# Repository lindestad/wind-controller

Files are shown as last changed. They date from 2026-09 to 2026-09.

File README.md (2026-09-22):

# LINDESTAD wind controller

Reproducible ESP32-C3 / Zephyr firmware and KiCad PCB for a four-fan simracing wind simulator.

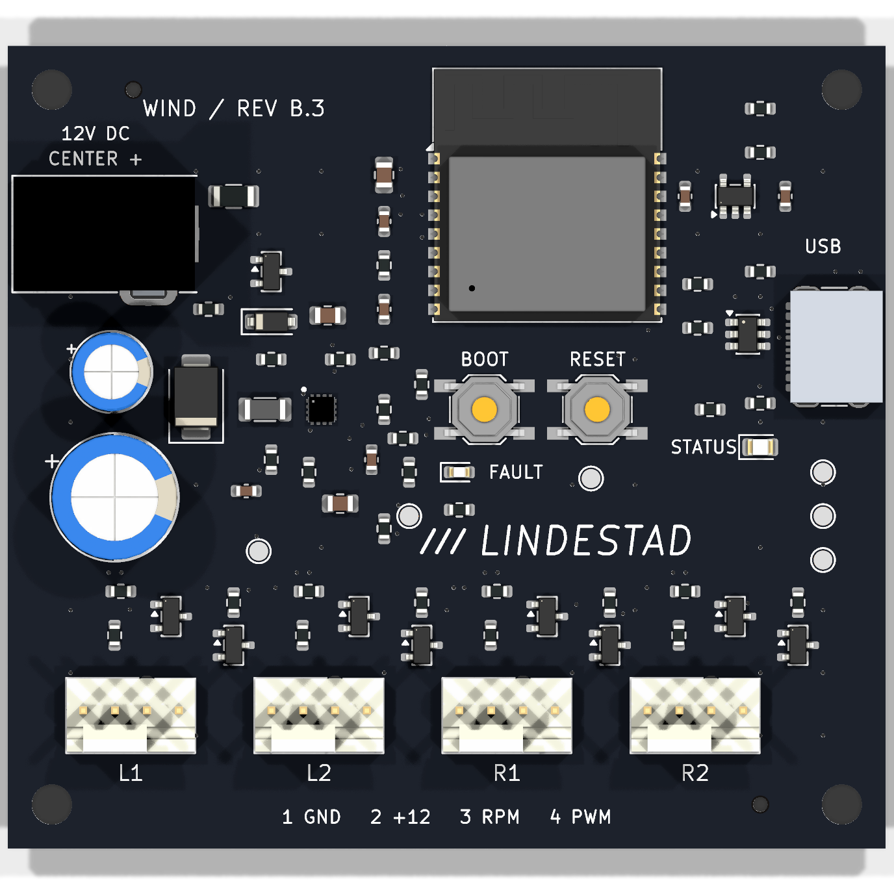
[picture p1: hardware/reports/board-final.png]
Populated WindPCB B.3 CAD render


[Hardware and manufacturing files](hardware/README.md) · [Schematic](hardware/reports/schematic.pdf) · [BOM](hardware/BOM.csv) · [Host integration](docs/host-integration.md)

The images are CAD renderings; representative USB/jack/eFuse models are visual aids.

Zephyr application for WindPCB B.3, ESP32-C3-WROOM-02-N4, four ARCTIC P14 Pro PST fans. Uses native USB Serial/JTAG, four 25 kHz hardware PWM outputs and four tach inputs. No external programmer is required for blank-flash recovery.

The assembled B.3 board is working. On 22 September 2026 it was programmed over native USB, tested with one and then two fans, and integrated with SimHub through Rig Companion. Live full-demand readings were approximately 2,470 and 2,410 RPM (fan rating 2,500 RPM); the user confirmed good airflow after correcting a reversed fan. This is functional bring-up evidence, not calibrated electrical or thermal qualification. See [validation scope](docs/validation.md).

## Repository layout

- `src/`, `include/`, `boards/`: firmware and custom Zephyr board definition.
- `hardware/`: native KiCad project, local libraries/models, BOM, Gerbers, CPL, STEP, PDFs, renders and exporter.
- `scripts/`, `tests/`: dependency setup, build, pin audit, stop-first flash and executable host tests.
- `integrations/simhub/`: source snapshot of the companion's SimHub bridge; no proprietary SDK DLLs.
- `reports/`: historical software/build/bring-up evidence, not a substitute for rerunning checks.

## Build

Windows workspace: `../wind-zephyr`, pinned to Zephyr **v4.4.2**. The required complete Zephyr SDK **1.0.1** is installed under `~/zephyr-sdk-1.0.1`. This project is a separate Git repository; SDK and dependency repositories are outside it.

Install Git, Python 3.12 (including `py`), CMake, Ninja and a host GCC (for the tests; Strawberry Perl's GCC works on Windows). Install the complete **Zephyr SDK 1.0.1** at `~/zephyr-sdk-1.0.1`, or pass its directory with `-Sdk`. Fetch the pinned source dependencies once:

```powershell
./scripts/setup.ps1
./scripts/build.ps1 -Pristine
../wind-zephyr/.venv/Scripts/python.exe tests/test_control.py
```

`build/zephyr/zephyr.bin` is the application build output. Use the Zephyr runner's generated flash configuration rather than guessing offsets. Build provenance and configuration checks are recorded in `reports/`. See `docs/validation.md` for scope and hardware acceptance items.

To recreate dependencies, create a Python 3.12 virtual environment in `../wind-zephyr/.venv`, install `west`, initialize the official Zephyr manifest at v4.4.2, run `west update`, install `zephyr/scripts/requirements.txt`, and run `west blobs fetch hal_espressif`. Use SDK 1.0.1. The frozen manifest is stored in `reports/west-frozen.yml`. No global Zephyr workspace was changed.

## USB and SimHub

Hold BOOT, press/release RESET, release BOOT. The ROM downloader should enumerate through USB-C even if application flash is blank. Connect a data-capable cable; barrel power is unnecessary for flashing. Run `west flash --esp-device COMx` from this workspace with the build directory specified, then press RESET if needed. The exact runner command is documented by `west flash -H -r esp32` and must match the installed esptool version. No eFuse/security programming or UART bridge is required.

For direct integration without Rig Companion, use SimHub **Custom Serial Devices**, sending ASCII `W,<left>,<right>\n` with integer demands 0–1000. The final character is one LF byte. Send every 100 ms or faster, including unchanged values. There is no Arduino/ShakeIt protocol emulation. USB returns the structured status frames below; Zephyr console/log noise remains disabled. Displaying warnings in SimHub needs a receiver/integration; transmission alone does not create a SimHub warning UI.

Zero and demands below 50 stop that side. A nonzero request first precharges for 750 ms, then attempts the commanded headers individually. Each gets a 250 ms full-speed kick; the next starts after at least 500 ms and three new filtered tach edges, or after a 2 s timeout if tach is absent. That timeout raises a per-header warning and advances the sequence, without stopping any output. Losing tach for 2 s after startup also warns while maintaining the requested duty. One to four fans may occupy any headers; no fan-count setting is required. Even zero fans produces warnings rather than a shutdown. Missing headers can delay later fans by 2 s each (up to 6.75 s from command to the fourth header's kick).

An empty header, stalled motor and broken tach wire cannot be distinguished electrically. Warnings mean **no tach while commanded**, not a confirmed missing fan. There are no repeated automatic startup kicks. Three new edges clear a warning; stopping that side clears its warning and the next start checks again. Do not hot-plug fans; switch off supplies before moving connectors.

Every 500 ms, USB transmits `S,1,<mode>,<mask>\n` (8 ASCII bytes). Version is 1; mode is `0` off, `1` precharging, `2` active (including warnings), `3` command timeout, or `4` fault. Mask is one uppercase hexadecimal digit: bits `1/2/4/8` correspond to L1/L2/R1/R2 without tach. For example `S,1,2,A\n` means active, with L2 and R2 warnings. Warnings are live and only apply after a startup attempt, so a clear mask at boot does not prove a fan is connected. STATUS stays lit when fan power is enabled. The red FAULT LED remains controlled by the hardware eFuse, not these firmware warnings.

Status transmission uses a bounded interrupt-driven buffer; a host that stops reading cannot block the control loop or command timeout. Pending reports can be stale after a host pause; a receiver must wait for fresh periodic reports before relying on them. Reports describe requested controller state, not measured fan-supply voltage or verified motor motion.

Only valid complete demand frames refresh the 500 ms command deadline. Overlong, malformed and partial frames are rejected. RX-budget saturation and output failures still stop operation and require reset; warnings do not bypass these protections. Commanded stop sets all PWM inputs low before removing fan power. Abrupt USB loss/reset can still cause the documented brief capacitor-powered twitch/coasting.

## Extended telemetry

Extended telemetry is also sent about once per second: `T,2,<mode>,<warning_hex>,<uptime_ms>,<accepted>,<rejected>,<rpm_L1>,<rpm_L2>,<rpm_R1>,<rpm_R2>,<pwm_L1>,<pwm_L2>,<pwm_R1>,<pwm_R2>\n`. RPM uses edge-count differences over the actual sample interval and assumes two pulses per revolution; absolute accuracy needs independent measurement. PWM values are per-header 0–1000 output demands including startup kicks. No supply voltage/current/temperature measurement exists. The existing S1 reports remain unchanged; consumers should ignore recognized additional report types. Rig Companion now owns USB and receives SimHub vehicle speed through its localhost bridge; see [host integration](docs/host-integration.md).

## Routine firmware updates

After building, use Rig Companion’s **Release USB for firmware update** button (or close any direct serial owner) and run `./scripts/flash.ps1 -Port COM4` (substitute the current port). The helper sends stop commands, requires repeated OFF reports for two seconds, then invokes the generated Zephyr flash runner. It aborts if it cannot confirm OFF. Firmware starts with fan power disabled and needs a new valid demand before running. Never resume the command sender during flashing.

The board's external enable pull-down is intended to keep incoming fan power off in ROM download/reset. This makes leaving 12 V connected a supported design intent for routine updates with the stop-first helper, **not a measured guarantee of no movement**: the MCU cannot measure output capacitor voltage, and reset can release PWM before stored energy drains. Disconnect 12 V whenever zero fan movement matters, or for blank/corrupt firmware recovery. The helper cannot work on older firmware without status reports. Hold BOOT/RESET and use the ordinary Zephyr runner with 12 V disconnected in that case.

The watchdog requests a whole-system reset. The ESP32 driver uses an interrupt stage followed by a reset stage; a configured 500 ms stage interval is approximately 1 s to hardware reset, not a 500 ms reset guarantee. The ordinary command timeout runs separately. No hardware runtime timing guarantee is claimed before measurement.

## Pin map

| Function | GPIO |
|---|---|
| L1/L2/R1/R2 PWM sink gates | 4 / 5 / 6 / 7 |
| L1/L2/R1/R2 tach | 0 / 1 / 3 / 20 |
| Fan power enable | 10 |
| Status LED | 21 |
| Native USB D− / D+ | 18 / 19 |
| BOOT | 9 |
| Reserved boot straps | 2 / 8 |

The DTS uses the WROOM N4 module definition, not a development board with UART0 on GPIO20/21. UART0/1, radios, logging and power management are disabled. The eFuse FLT signal is not wired to the MCU, so firmware cannot classify its faults or measure supply voltage/current.

The LEDC child `inverted` property initializes the stopped output high. Runtime requests use normal polarity and `(1000 − fan_demand) × 40 ns` gate pulse width; the transistor provides the physical inversion. The pinned driver's implementation was checked to distinguish initial idle level from runtime polarity flags.

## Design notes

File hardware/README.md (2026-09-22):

# WindPCB B.3 — editable hardware and manufacturing release

70 × 64 mm, black solder mask, white silkscreen, two-layer 1.6 mm FR-4 / 1 oz copper.
ESP32-C3-WROOM-02-N4; four ARCTIC P14 Pro PST headers; native USB-C; protected 12 V input.

Populated PCB CAD rendering
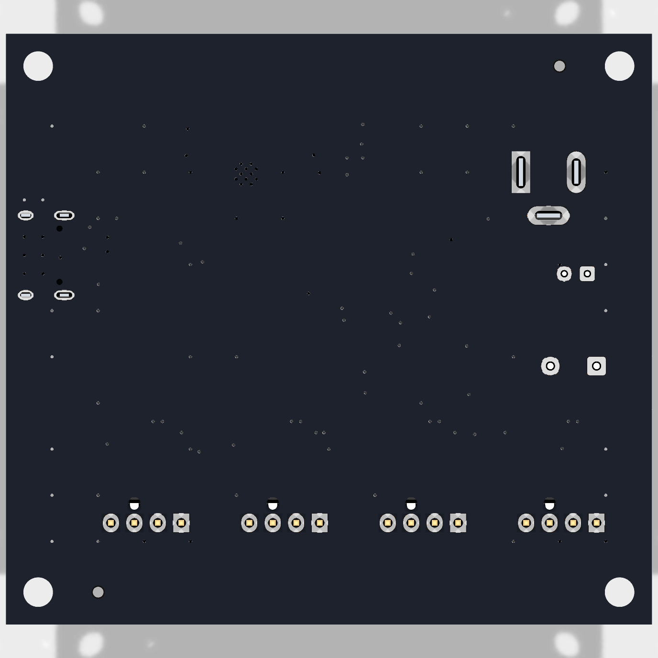
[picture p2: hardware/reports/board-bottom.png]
Underside CAD rendering


These are CAD renders, not photographs. J1, J2 and U4 have representative visual bodies;
their manufacturer drawings and electrical pads govern assembly.

## Reproduce the board

1. Install **KiCad 10.0**, including its standard symbol, footprint and 3D libraries.
2. Open `windpcb.kicad_pro`. All project-specific symbols, footprints and visual models
   are under `libraries/`; library tables use `${KIPRJMOD}`. Standard STEP models use
   `${KICAD10_3DMODEL_DIR}`. No files from the author's KiCad folder are needed.
3. Use [BOM.csv](BOM.csv), [schematic PDF](reports/schematic.pdf) and
   [assembly drawing](reports/assembly-top.pdf) to inspect the release.
4. Fabrication input: [Gerber ZIP](manufacturing/windpcb-revb-gerbers.zip), including
   copper, masks, silkscreens, outline, separate PTH/NPTH drilling and front paste.
5. Full assembly inputs: [PCBA BOM](manufacturing/assembly/PCBA-BOM.csv) and
   [PCBA CPL](manufacturing/assembly/PCBA-CPL.csv): **70 placements, 33 MPNs,
   63 SMT + 7 through-hole**. Do not use the SMT-only files for full assembly.
6. Select black mask / white silk, lead-free HASL, top-side assembly, and customer-added
   tooling holes. Retain individual placement review. Firmware is flashed afterward.

J1 takes a **5.5 × 2.5 mm centre-positive 12 V** barrel plug. Use a regulated supply
with sufficient startup margin (at least 3 A recommended). Each fan has its own header;
leave PST daisy-chain sockets unused. Pin order: **1 GND, 2 +12 V, 3 tach, 4 PWM**.

## Placement and process review

The included CPL is the original submitted file, with explicit connector/capacitor
insertion-origin offsets. **JLC subsequently corrected several component orientations
in its own assembly system. The final numeric machine placement file was not supplied.**
This release therefore requires a fresh supplier placement review; uploading the CPL
alone does not reproduce that approval. Verify every polarized part/pin 1 against the
native CAD and assembly drawing, especially Q1–Q9, U2/U3/U4, J2–J6, D1–D4 and C6/C9.
The first assembled board has since operated successfully with the firmware.

U4 TPS25970LRPWR has ten electrical terminals, even when a supplier's generic visual
model shows sixteen leads. Its 16 split paste apertures are intentional. Preserve the
TI-derived RPW0010A lands and 0.100 mm stencil prescription; ask the assembler to review
the eFuse, USB-C, and ESP32 thermal-via soldering process for its selected finish.

H1–H4: 3.2 mm M3 mounting holes, 63 × 57 mm spacing. H5/H6 are 1.152 mm NPTH tooling
holes with 0.148 mm mask expansion. Their centres are (10, 3.5) and (60, 60.5) mm from
the upper-left corner. The CPL origin is the lower-left corner; X right, Y up.

## Regenerate and verify

Run the exporter with KiCad's Python (which provides `pcbnew`). On Windows:

```powershell
& 'C:/Program Files/KiCad/10.0/bin/python.exe' -m pip install --target hardware/tools/vendor -r hardware/tools/requirements.txt
& 'C:/Program Files/KiCad/10.0/bin/python.exe' hardware/tools/export.py
```

On another installation, put `kicad-cli` on PATH or set `KICAD_CLI` and use a Python
environment that can import KiCad 10's `pcbnew`. The exporter runs ERC, full DRC with
schematic parity, checks every pad/net, exports manufacturing files/BOM/CPL, PDFs,
board-only STEP, pictures and SHA256 hashes. It does **not** rebuild or reroute the PCB.
Historical one-time layout generators were deliberately not included as build steps.

Engineering specifications and revision notes are in `docs/`. Their pre-order wording
and references to historical local reports describe earlier reviews, not the current
hardware test status. The root README and `docs/validation.md` describe current tests.
Private supplier order/account records are not part of this public release.

Sources: [TI TPS2597](https://www.ti.com/lit/ds/symlink/tps2597.pdf),
[ARCTIC P14 Pro PST](https://support.arctic.de/p14-pro-pst),
[JLC tooling guide](https://jlcpcb.com/help/article/how-to-add-tooling-holes-for-pcb-assembly-order).

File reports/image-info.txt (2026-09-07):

esptool v5.4.0
Image size: 133780 bytes
Detected image type: ESP32-C3

ESP32-C3 Image Header
=====================
Image version: 1
Entry point: 0x40381344
Segments: 3
Flash size: 4MB
Flash freq: 80m
Flash mode: DIO

ESP32-C3 Extended Image Header
==============================
WP pin: 0xee (disabled)
Flash pins drive settings: clk_drv: 0x0, q_drv: 0x0, d_drv: 0x0, cs0_drv: 0x0, hd_drv: 0x0, wp_drv: 0x0
Chip ID: 5 (ESP32-C3)
Minimal chip revision: v0.0, (legacy min_rev = 0)
Maximal chip revision: v655.35

Segments Information
====================
Segment   Length   Load addr   File offs  Memory types
-------  -------  ----------  ----------  ------------
      0  0x01554  0x3fc886c0  0x00000018  DRAM, BYTE_ACCESSIBLE
      1  0x086b0  0x40380000  0x00001574  IRAM
      2  0x00024  0x50000000  0x00009c2c  RTC_IRAM, RTC_DRAM

ESP32-C3 Image Footer
=====================
Checksum: 0x3f (valid)

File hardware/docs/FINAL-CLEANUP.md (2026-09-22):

# Revision B — final labels and solder-pad correction

Historical revision B document. The executed review is in [REPORT.md](reports/preorder-review/REPORT.md); current B.1 corrections and validation are in [REVIEW-RESOLUTION.md](REVIEW-RESOLUTION.md).

6 September 2026, after the $82.72 quotation. Current board/manufacturing files supersede the uploaded Gerbers. No new quote or order was submitted in this cleanup.

## Labels and test point

TP5 (FAULT_N) moved 3.5 mm right: (43, 34.5) to (46.5, 34.5) mm from the top-left outline. FAULT is now right of D4, aligned with the LED; STATUS is left of D3. The FAULT_N branch and nearby 3.3 V track bends were adjusted locally and pours refilled. Position metadata is updated. Circuit topology, values, outline and SMT placements did not change.

## Missing 3D body

The boxed component is **U4, TPS25970LRPWR**, the fan-power protection IC. Its ten numbered pads, nets, custom footprint, schematic symbol, BOM entry C3662801 and SMT placement are present. It has no attached 3D model, so KiCad displays lands without a body. JLC included U4 in the quote. J2 also lacks a local 3D body. Neither absence means an omitted component; use manufacturer dimensions to review mechanical envelopes.

## Underside rings: real solder-mask defect

The soldered through-hole pads had copper layers but **no F.Mask or B.Mask openings**, in both board and project footprint copies. The copper itself was not unusually narrow; mask would cover the soldering surface. The render exposed a genuine manufacturing defect that the earlier clean ERC/DRC did not detect.

Restored both-face mask openings with **0.05 mm expansion per edge** for all 23 hand-solder joints and four USB-C shell pads. Updated local libraries as well as the board. Copper sizes, drills and paste geometry are unchanged. U1's deliberately covered thermal holes are excluded.

| Feature | Copper pad, mm | Hole/slot, mm | Narrowest nominal ring |
|---|---|---|---:|
| J3–J6 fan contacts | 2.03 × 1.73 | 1.02 round | 0.355 mm |
| C6 | 1.60 × 1.60 | 0.80 round | 0.400 mm |
| C9 | 2.00 × 2.00 | 1.00 round | 0.500 mm |
| J1 contact 1 | 4.60 × 2.00 | 3.60 × 1.00 slot | 0.500 mm |
| J1 other contacts | 4.20 × 2.00, rotated as appropriate | 3.20 × 1.00 slot | 0.500 mm |
| J2 shell tabs, factory assembly | 2.10 × 1.00 or 1.60 × 1.00 | 1.70 × 0.60 or 1.20 × 0.60 slot | 0.200 mm |

These are nominal dimensions before fabrication tolerances. The 0.355–0.500 mm hand-solder rings provide enough nominal land to retain the copper geometry; mask exposure was the required correction. USB shell pads retain their narrower connector lands, now exposed. Ground thermal reliefs remain. NPTH mounts/locators/tooling holes did not acquire copper.

## Verification and release

- Regenerated ERC, full DRC/parity and exact pad-net comparison: pass, no violations or unconnected items.
- Audited all 27 soldered PTH pads in board and local libraries for mask layers/expansion.
- Parsed both mask Gerbers and checked **54 pad openings**, coordinates and aperture dimensions. See `reports/solder-pad-mask-audit.json`; `tools/validate_b.py` repeats this audit.
- Inspected updated top/underside renders, including LED labels and exposed solder surfaces.
- Regenerated Gerbers, drills, drawings, board-only STEP, previews and hashes. BOM and SMT CPL remain identical to the quoted versions; TP5 has no purchased component.
- Added `PREORDER-REVIEW-PLAN.md`, a proposed agent review and testing workflow that has not been executed.

Old quoted files/manifest are in `reports/jlcpcb/quoted-inputs/`. Use the current `manufacturing/windpcb-revb-gerbers.zip` for a later submission; the JLC draft still contains older Gerbers. A.1 is retained unchanged and has not received this fix. Cost inputs are unchanged, but a revised live price has not been verified.

Corrected underside

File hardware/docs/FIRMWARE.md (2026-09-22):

# Zephyr and SimHub interface

Hardware revision B.3 uses ESP32-C3-WROOM-02-N4 (4 MB flash). Firmware is implemented in the separate local Git repository [wind-controller](../../README.md), commit `6777767`. On 7 September 2026 the actual custom-board build passed with Zephyr v4.4.2 and SDK 1.0.1; 19 host tests and 42 generated-build/hardware-pin checks passed. This is software feasibility evidence, not a test on manufactured hardware. The native USB Serial/JTAG peripheral supports the ROM downloader independently of application firmware; no external USB-UART or debug probe is required.

## Pin map

| Signal | ESP32-C3 GPIO | Module pad | Behaviour |
|---|---:|---:|---|
| L1 PWM drive | 4 | 3 | Transistor gate, inverted relative to fan PWM |
| L2 PWM drive | 5 | 4 | Same |
| R1 PWM drive | 6 | 5 | Same |
| R2 PWM drive | 7 | 6 | Same |
| Fan power enable | 10 | 10 | High enables eFuse; external pull-down and RC |
| L1 tach | 0 | 18 | Non-inverting MOSFET-translated input, 2.2k to 3.3 V |
| L2 tach | 1 | 17 | Same |
| R1 tach | 3 | 15 | Same |
| R2 tach | 20 | 11 | Same; do not enable UART RX here |
| Status LED | 21 | 12 | High lights green LED; ROM UART TX may pulse it |
| USB D− | 18 | 13 | Dedicated native USB |
| USB D+ | 19 | 14 | Dedicated native USB |
| BOOT | 9 | 8 | Pull-up, button shorts to ground |
| Other boot straps | 8 / 2 | 7 / 16 | Pull-ups; reserve these GPIOs |
| RESET | EN | 2 | Pull-up/RC, button shorts to ground |

The red FAULT LED and TP5 report the eFuse fault signal. **It is not connected to an MCU input.** The hardware has no voltage ADC, current telemetry or automatic fault classification. Tach readings can detect a fan that remains stopped after a commanded startup, but cannot identify every cause.

## First flash and recovery

1. Connect USB-C with a data-capable cable; barrel power is unnecessary.
2. Hold BOOT, press and release RESET, then release BOOT. This enters the ROM USB downloader even with blank or broken firmware.
3. Flash through the enumerated USB serial port using Zephyr's Espressif runner/esptool. The implemented custom board target is `wind_controller/esp32c3`, with 4 MB flash and this pin map. Build instructions and generated-runner evidence are in the firmware repository.
4. Press RESET to run. If the runner leaves the C3 in download mode, use its documented watchdog-reset option or press RESET; ordinary serial RTS/DTR assumptions from USB-UART boards do not always apply.

Do not disable ROM download mode, USB Serial/JTAG, or burn security eFuses during ordinary provisioning. Do not use deep sleep, which can disconnect native USB. A COM port is expected; arbitrary USB HID/composite emulation is not the purpose of the C3's fixed Serial/JTAG peripheral.

## Required application behaviour

- Disable radios and configure the native USB Serial/JTAG UART driver; do not blindly reuse the DevKitM external UART console configuration. Keep diagnostic logging out of the command stream.
- Leave fan enable low during all initialization. Configure four LEDC PWM outputs at 25 kHz, initially with their **GPIO gates high**, which holds the fan PWM pins low. Enable power only after a valid command. Hold all four PWM pins at zero for 750 ms after enable, allowing the approximately 364 ms nominal ramp to finish. Then start individual fans as described below; actual spin-up takes longer.
- A 100% fan command means the transistor remains off (gate low). A 0% fan command means gate high. PWM flags or duty conversion must account for this inversion exactly once.
- Use hardware PWM, not a thread repeatedly toggling GPIOs. All four outputs use the same frequency and can share a suitable timer.
- Tach inputs are independent. Start with two pulses per revolution, verify on the actual fans, and calculate `RPM = pulse_frequency × 30` only after that verification. Debounce/filter implausibly short pulses in software.
- Never start on enumeration, console noise, malformed input or button use alone. Reject out-of-range values and overlong frames. Use a whole-system watchdog reset, no GPIO hold and no retained PWM/enable state. CPU-only reset is insufficient. Verify the actual reset domain and pin waveforms on hardware.
- Initial command timeout: 500 ms. On timeout, command PWM stop and disable fan power. No endless fault auto-retry. Output capacitance discharges over time; electrical power removal is not instantaneous.

## SimHub contract

Use **Custom Serial Devices**, with the implemented frame `W,<left>,<right>\n`, where both values are integers 0–1000. Examples: `W,0,0\n`, `W,500,500\n`, `W,1000,700\n`. The `\n` here denotes an actual LF byte, not two literal characters. End-to-end SimHub/USB operation remains a first-board check.

Send complete fresh frames at 10 Hz or faster, even if unchanged; disable Changes only. A paid SimHub configuration may use 20 Hz. Malformed or partial traffic must never refresh the 500 ms timer. Map left to L1/L2 and right to R1/R2. SimHub's actual wind-effect expressions and the Zephyr parser must be implemented and tested together. A serial port alone does not implement SimHub's Arduino/ShakeIt protocol; no compatibility with that protocol is claimed.

References: [Zephyr ESP32-C3](https://docs.zephyrproject.org/latest/boards/espressif/esp32c3_devkitm/doc/index.html), [Espressif native USB](https://docs.espressif.com/projects/esp-idf/en/stable/esp32c3/api-guides/usb-serial-jtag-console.html), [SimHub Custom Serial Devices](https://github.com/SHWotever/SimHub/wiki/Custom-serial-devices).

## B.1 startup, stop and fault sequence

The following contract is implemented in the separate firmware repository. Updated 22 September 2026: missing/stalled tach is a warning rather than a global shutdown, allowing any number of fans. The current firmware passes 25 host tests and 43 build checks and has been flashed and USB-tested on the first board. See the firmware repository's `docs/validation.md` for exact physical-test scope.

1. Earliest initialization: FAN_ENABLE low, four PWM sink gates high, radios disabled. Disable UART0 on the reused tach/status pins and reserve the native USB pins. Do not assert fan enable in bootloader or console initialization.
2. A complete valid nonzero frame starts PRECHARGE: keep all fan PWM pins low, assert enable and wait 750 ms. Continue processing command freshness throughout the wait; never sleep in a way that blocks the safety loop. Zero/zero or a 500 ms timeout immediately takes the stop path.
3. Attempt one commanded header at a time, in L1, L2, R1, R2 order. Apply a 250 ms 100% startup kick, then transition to requested duty. Advance after three new filtered tach edges and at least 500 ms, or after 2 s without qualified tach. On timeout set a no-tach warning for that header and continue starting the others; keep its requested PWM without repeated kicks. These provisional timing limits must be calibrated on the actual P14 Pro PST. Skip a stopped side.
4. Valid recurring frames update targets/freshness without restarting the precharge timer or startup stage. If a previously stopped fan is requested while others run, pass it through the same sequential startup queue. Never assume simultaneous motors' startup current equals their rated current.
5. Stop path: drive all four sink gates high (fan PWM = 0%), then deassert enable. A safety-loop service interval at most 10 ms gives an intended stale-command response within 510 ms of the last completed valid frame. Keep PWM low while logic power remains. On abrupt reset or USB loss, stored capacitor energy may cause a brief twitch/coasting; no instantaneous mechanical-stop promise is made.
6. Tach loss for 2 s raises a per-header warning and leaves outputs running. Three new edges clear it; stopping a side clears its warnings and a later start checks again. Missing fan, stall and broken tach wire cannot be distinguished. RX-budget exhaustion and actuator failures still stop operation and require reset. U4 FLT is not connected to the MCU, and OVLO does not assert FLT: tach alone cannot classify power faults. OVLO may require barrel power cycling.
7. Feed the hardware watchdog only when the control/safety loop is healthy. Logging, USB congestion or parser work must not block deadlines. On recovery discard buffered commands. The simple W frame has no session authentication or anti-replay claim; neither is required for this locally connected accessory.

Tach polarity is unchanged by the common-gate level shifters. Two pulses/revolution remains a first-board measurement, not a guaranteed value inferred from connector convention.

USB now transmits `S,1,<mode>,<mask>\n` every 500 ms using bounded interrupt-driven TX. Mode 0=OFF, 1=PRECHARGE, 2=ACTIVE (possibly warning), 3=STALE, 4=FAULT. Mask is one uppercase hexadecimal digit with L1/L2/R1/R2 bits 1/2/4/8. Console logging remains disabled. A warning display in SimHub requires receiver integration. STATUS still indicates requested fan power; FAULT is still the independent hardware LED.

For routine updates, the firmware repository provides `scripts/flash.ps1 -Port COM4`: send stop, require repeated OFF reports for two seconds, then run the generated Zephyr flash command. USB powers the MCU independently of the 12 V fan rail, so normal 12 V power may remain connected during flashing. ROM recovery is retained and no security/eFuse settings are changed. Reset may allow brief residual fan movement; unplug 12 V if no movement is required. The helper cannot confirm OFF on older, blank or broken firmware; use BOOT/RESET recovery in that case.

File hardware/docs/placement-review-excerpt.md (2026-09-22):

# Factory placement reference (8 September 2026)

The final factory-adjusted placement was reviewed for all 70 components. The submitted CPL was not rewritten after JLC adjusted it. Always review a new supplier placement against the schematic and pads.

## U4 — the component in the user's image

The assigned part is **TI TPS25970LRPWR, C3662801, VQFN-10-HR, 2 × 2 mm**. Its model in the viewer has sixteen decorative perimeter leads. Those are not the physical terminal pattern and must not be used to rotate the component.

With the model hidden, the actual land pattern has the correct ten electrical terminals: four small terminals on each side and two long inner power lands. It agrees with TI's RPW0010A land-pattern drawing. The model is centered over that pattern; its marking is in the upper-left corner, consistent with the required real pin-1 location. This supports the displayed orientation; the generic model cannot demonstrate the shape of every hidden terminal.

Required pin map, also verified against the native board:

| Position | Pin and function |
|---|---|
| Upper-left | 1 EN, at (24.1, 28.3) |
| Left side downward | 2 OVLO, 3 DNC, 4 FLT |
| Inner long land, left | 5 IN |
| Inner long land, right | 6 OUT |
| Right side upward | 7 DVDT, 8 GND, 9 ILM, 10 ITIMER |

The processed PCB CAM archive retains **16 split paste openings** around U4; these are stencil apertures, not sixteen electrical pins. All 199 paste features and all 22 custom paste-symbol geometries are unchanged between its original and edited CAM steps after resolving reordered symbol indices.

**Disposition:** no U4 rotation or footprint change indicated. The rendering mismatch is visual. The actual laser-cut stencil thickness and assembly machine program are not established by the PCB CAM archive or this generic overlay.

Evidence: [U4 with model](U4.png), [actual U4 lands](U4-pads.png), [processed copper](u4-factory.png), [paste audit](paste-audit.json), [TI RPW land drawing](../preorder-review/reviewer-c/sources/tps2597-p52.png), [TI datasheet](https://www.ti.com/lit/ds/symlink/tps2597.pdf).

## Orientation and polarity findings

| References | Final observation and result |
|---|---|
| Q1 | Correct: pin 1/gate upper-left, pin 2/source lower-left, single pin 3/drain right. All three leads overlay the intended pads. The original 180° mismatch is resolved. |
| Q2, Q3, Q4, Q5 | Each individually checked: gate upper-left, source/GND lower-left, drain/PWM right; leads aligned. |
| Q6, Q7, Q8, Q9 | Each individually checked: gate/+3V3 upper-left, source/MCU tach lower-left, drain/fan tach right; leads aligned. |
| U2 | Correct: two terminals at top, three at bottom; pin 1/VIN bottom-left, pin 2/GND bottom-middle, pin 3/EN bottom-right, pin 5/VOUT top-left. |
| U3 | Correct: three terminals on each side, pin 1 upper-left. Pin 2/GND left-middle, pin 5/VBUS right-middle. All six leads aligned. |
| U1 | Correct: antenna toward top edge; module pin 1 upper-left; both nine-pad perimeter rows aligned. The decorative shield dot at bottom-left is not module pin 1. |
| J1 | Correct part DC-005-5A-2.5/C381115; opening left. Asymmetric terminal layout agrees: center-positive pin 1 right, switched pin 2 left, sleeve/GND pin 3 below. |
| J2 | Correct HRO TYPE-C-31-M-12/C165948, opening right. The final drawing's signal contacts overlap their lands; both locating-post markers register with the holes and all four shell features register with their slots. No remaining offset requiring a shift was found. See qualification below. |
| J3, J4, J5, J6 | Each individually checked: electrical pin 1 at left, then +12V, RPM, PWM. Friction lock faces the bottom board edge. Locating feature is above pin 3, over the intended NPTH, rather than on the opposite side as in the old preview. |
| C6 | Positive lead at left (7,26); negative at right (9.5,26). Positive marker and right-side negative stripe agree. |
| C9 | Positive lead at left (6,36); negative at right (11,36). Positive marker and right-side negative stripe agree. |
| D1 | Cathode/band **left**, connected to VIN_PROTECTED; anode right to RP_GATE. Correct. |
| D2 | Cathode/band **bottom**, connected to VIN_PROTECTED; anode top to GND. Correct; the downward cathode is intentional. |
| D3 | Cathode **left** to GND; anode right to LED_A. Correct. |
| D4 | Cathode **left** to FAULT_N; anode right to FAULT_LED_A. Correct. |
| SW1, SW2 | Four leads align; upper and lower contact-pair axis agrees with the footprint. No quarter-turn error. |
| All 32 resistors | Individually checked, both ends on their intended pads. No missing, displaced, or quarter-turn part observed. Reversed lettering on nonpolar parts is harmless. |
| C1–C5, C7, C8, C10, C11 | All nine nonpolar ceramics individually checked; correct part assignment and two-pad alignment. |
| F1, FB1 | Both nonpolar parts individually checked; correct assignment and alignment. |

The UI explicitly flags 14 references as engineer-modified: Q1–Q9, J3–J6 and U3. The final physical orientation was checked for *all* components, including U2 and J2, regardless of whether the UI flagged them.

JLC's [assembly FAQ](https://jlcpcb.com/help/article/pcb-assembly-faqs-part-2) explains that its colored dot denotes a component marking, not universally electrical pin 1; diode `+`/`−` means anode/cathode, and capacitor `+` means positive. Accordingly, the review used actual lead positions and native pad nets as well as these annotations.

### USB-C qualification

[Final component overlay](J2.png) and [bare lands at the same zoom](J2-pads.png) show simultaneous registration of the signal row, posts and shell slots. The exposed gray toe beyond each yellow contact is not, by itself, a displaced contact; a solder land is deliberately longer than the contact.

The retained [exact HRO drawing](../final-checks/C165948.png) specifies 5.78 mm locating-post spacing and 4.18 mm separation between shell rows; these agree with the native geometry. Native post centers are (64.2,21.11) and (64.2,26.89); shell centers have X63.67/67.85 and Y19.68/28.32. All seven connector slots (four USB, three jack) retained their centers, axes and straight centerline lengths during factory CAM processing. No blind model-origin shift or PCB revision is indicated.

This is a dimensional/visual registration check, not a measurement of supplied physical connector tolerances. The supplier model is still not a substitute for its mechanical drawing.

## Factory-file checks

Reproducible scripts and machine-readable results are retained beside this report.

| Check | Result |
|---|---|
| Original layers in factory ZIP versus current submitted manufacturing layers | Byte-identical for every corresponding file, including copper, masks, silk, outline, paste and drills. |
| Source PCB/BOM/CPL/release hashes | Unchanged from the previous reviewed B.3 release; see `hashes.json`. |
| Board outline | Same 70 × 64 mm rectangular centerline; factory line width is plotting width, not an increase in board dimensions. |
| Top and bottom copper | Compared at 20 µm/pixel with a two-pixel (40 µm per-axis) boundary tolerance. No additions beyond that tolerance inside the board. All larger removals are confined to existing non-plated-hole clearance regions. No other trace/pad change was detected at that resolution. |
| Top and bottom solder mask | No differences beyond the same tolerance. |
| Round holes | All 148 intended round-hole centers present, with no extras. Maximum matching error 0.000590 mm. |
| Slotted holes | All seven present; centers, axes and straight centerline lengths match within 0.001 mm. |
| Drill tool diameters | CAM diameters differ by approximately 0, +0.05, +0.13 or +0.15 mm, depending on hole group; slot cutter widths are about +0.151 mm. These are tool/CAM dimensions, not independent measurements of finished plated bores. No center shift or missing hole was found. |
| Paste in embedded CAM archive | All 199 original/edited features match after resolving symbol-index changes; 22 custom aperture geometries unchanged, including U4's 16 split apertures. |

The copper test excludes the outermost 0.30 mm to avoid factory plotting-border differences. It is a raster geometry comparison, **not a formal netlist-equivalence proof**. It does not establish finished-hole tolerances, stencil thickness, solder quantity, AOI/X-ray outcomes, or actual machine-program coordinates. The silkscreen was inspected visually in the final viewer; it was not subjected to the same numerical comparison.

## Recommendation

There is no remaining observed component-orientation, polarity, missing-part or USB/header registration issue that warrants another correction request. U4's generic artwork is not a reason to rotate it or change the PCB. The earlier reference-preview rotation offsets must **not** be applied again to this corrected final placement.

If the user wants additional factory assurance, the remaining targeted subject would be actual U4 stencil/process execution (including the specified 0.100 mm stencil approach), rather than asking for another visual rotation change. This review does not claim that such manufacturing-process assurance has been received. No support contact or approval has been made on the user's behalf.

## Evidence index

- `dfm-final-overview.png`: final live viewer, restored to the full labeled board.
- `sheet-1.png` through `sheet-6.png`: inspection contact sheets; individual full-resolution `<reference>.png` files retain the detailed views for all 70 parts.
- `U4-pads.png`, `J2-pads.png`, `J3-pads.png`: component-hidden views.
- `dfm-rows.json`, `bom-audit.json`: actual final table and automated assignment check.
- `hole-audit.json`, `raster-comparison.json`, `paste-audit.json`, `hashes.json`: factory comparison evidence.
- `factory/`: extracted downloaded ZIP, preserved for traceability.
- Previous native pin and net audit: [pad-audit.json](../placement-review/pad-audit.json).

## Individual component record

Every row below has its own saved browser image. “Aligned” means no visible placement discrepancy found against the intended pads; it does not certify solder-joint quality.

| Reference | Actual assigned part | Assembly | Individual review |
|---|---|---|---|
| [C1](C1.png) | CL10A105KB8NNNC / C15849 | SMT Assembly | Nonpolar; both terminations aligned with intended pads. |
| [C2](C2.png) | CL10A105KB8NNNC / C15849 | SMT Assembly | Nonpolar; both terminations aligned with intended pads. |
| [C3](C3.png) | GRM21BR61H106KE43L / C440198 | SMT Assembly | Nonpolar; both terminations aligned with intended pads. |
| [C4](C4.png) | CC0603KRX7R9BB104 / C14663 | SMT Assembly | Nonpolar; both terminations aligned with intended pads. |
| [C5](C5.png) | CL10A105KB8NNNC / C15849 | SMT Assembly | Nonpolar; both terminations aligned with intended pads. |
| [C6](C6.png) | EEUFR1H470 / C407950 | Wave Soldering | Positive left, negative stripe right; centered over lead pair. |
| [C7](C7.png) | CL21B105KBFNNNE / C28323 | SMT Assembly | Nonpolar; both terminations aligned with intended pads. |
| [C8](C8.png) | CC0603KRX7R9BB104 / C14663 | SMT Assembly | Nonpolar; both terminations aligned with intended pads. |
| [C9](C9.png) | EEUFR1E471 / C407944 | Wave Soldering | Positive left, negative stripe right; centered over lead pair. |
| [C10](C10.png) | CL21B105KBFNNNE / C28323 | SMT Assembly | Nonpolar; both terminations aligned with intended pads. |
| [C11](C11.png) | CC0603KRX7R9BB104 / C14663 | SMT Assembly | Nonpolar; both terminations aligned with intended pads. |
| [D1](D1.png) | BZT52C9V1-7-F / C260913 | SMT Assembly | Cathode/band left; aligned. |
| [D2](D2.png) | SMBJ15A / C83846 | SMT Assembly | Cathode/band bottom; aligned. |
| [D3](D3.png) | KT-0805G / C2297 | SMT Assembly | Cathode left; aligned. |
| [D4](D4.png) | KT-0603R / C2286 | SMT Assembly | Cathode left; aligned. |
| [F1](F1.png) | 0466003.NRHF / C14165 | SMT Assembly | Nonpolar; both terminations aligned with intended pads. |
| [FB1](FB1.png) | BLM31PG121SN1L / C85841 | SMT Assembly | Nonpolar; both terminations aligned with intended pads. |
| [J1](J1.png) | DC-005-5A-2.5 / C381115 | Wave Soldering | Opening left; correct asymmetric jack registration. |
| [J2](J2.png) | TYPE-C-31-M-12 / C165948 | SMT Assembly | Opening right; signal contacts, both posts and four shell slots register. |
| [J3](J3.png) | 470531000 / C240840 | Wave Soldering | Pin 1 left, locator above pin 3, lock toward bottom; aligned. |
| [J4](J4.png) | 470531000 / C240840 | Wave Soldering | Pin 1 left, locator above pin 3, lock toward bottom; aligned. |
| [J5](J5.png) | 470531000 / C240840 | Wave Soldering | Pin 1 left, locator above pin 3, lock toward bottom; aligned. |
| [J6](J6.png) | 470531000 / C240840 | Wave Soldering | Pin 1 left, locator above pin 3, lock toward bottom; aligned. |
| [Q1](Q1.png) | AO3401A / C15127 | SMT Assembly | Pin 1 upper-left, two terminals left / single drain right; aligned. |
| [Q2](Q2.png) | SI2312-TP / C6488168 | SMT Assembly | Pin 1 upper-left, two terminals left / single drain right; aligned. |
| [Q3](Q3.png) | SI2312-TP / C6488168 | SMT Assembly | Pin 1 upper-left, two terminals left / single drain right; aligned. |
| [Q4](Q4.png) | SI2312-TP / C6488168 | SMT Assembly | Pin 1 upper-left, two terminals left / single drain right; aligned. |
| [Q5](Q5.png) | SI2312-TP / C6488168 | SMT Assembly | Pin 1 upper-left, two terminals left / single drain right; aligned. |
| [Q6](Q6.png) | SI2312-TP / C6488168 | SMT Assembly | Pin 1 upper-left, two terminals left / single drain right; aligned. |
| [Q7](Q7.png) | SI2312-TP / C6488168 | SMT Assembly | Pin 1 upper-left, two terminals left / single drain right; aligned. |
| [Q8](Q8.png) | SI2312-TP / C6488168 | SMT Assembly | Pin 1 upper-left, two terminals left / single drain right; aligned. |
| [Q9](Q9.png) | SI2312-TP / C6488168 | SMT Assembly | Pin 1 upper-left, two terminals left / single drain right; aligned. |
| [R1](R1.png) | 0603WAF5101T5E / C23186 | SMT Assembly | Nonpolar; both terminations aligned with intended pads. |
| [R2](R2.png) | 0603WAF5101T5E / C23186 | SMT Assembly | Nonpolar; both terminations aligned with intended pads. |
| [R3](R3.png) | 0603WAF220JT5E / C23345 | SMT Assembly | Nonpolar; both terminations aligned with intended pads. |
| [R4](R4.png) | 0603WAF220JT5E / C23345 | SMT Assembly | Nonpolar; both terminations aligned with intended pads. |
| [R5](R5.png) | 0603WAF1002T5E / C25804 | SMT Assembly | Nonpolar; both terminations aligned with intended pads. |
| [R6](R6.png) | 0603WAF1002T5E / C25804 | SMT Assembly | Nonpolar; both terminations aligned with intended pads. |
| [R7](R7.png) | 0603WAF1002T5E / C25804 | SMT Assembly | Nonpolar; both terminations aligned with intended pads. |
| [R8](R8.png) | 0603WAF1002T5E / C25804 | SMT Assembly | Nonpolar; both terminations aligned with intended pads. |
| [R9](R9.png) | 0603WAF1001T5E / C21190 | SMT Assembly | Nonpolar; both terminations aligned with intended pads. |
| [R10](R10.png) | 0603WAF4701T5E / C23162 | SMT Assembly | Nonpolar; both terminations aligned with intended pads. |
| [R11](R11.png) | RT0603BRE0797K6L / C862326 | SMT Assembly | Nonpolar; both terminations aligned with intended pads. |
| [R12](R12.png) | RT0603BRD0710KL / C95204 | SMT Assembly | Nonpolar; both terminations aligned with intended pads. |
| [R13](R13.png) | 0603WAF2401T5E / C22940 | SMT Assembly | Nonpolar; both terminations aligned with intended pads. |
| [R14](R14.png) | 0603WAF1001T5E / C21190 | SMT Assembly | Nonpolar; both terminations aligned with intended pads. |
| [R15](R15.png) | 0603WAF1002T5E / C25804 | SMT Assembly | Nonpolar; both terminations aligned with intended pads. |
| [R16](R16.png) | 0603WAF4701T5E / C23162 | SMT Assembly | Nonpolar; both terminations aligned with intended pads. |
| [R17](R17.png) | 0603WAF1002T5E / C25804 | SMT Assembly | Nonpolar; both terminations aligned with intended pads. |
| [R18](R18.png) | 0603WAF2201T5E / C4190 | SMT Assembly | Nonpolar; both terminations aligned with intended pads. |
| [R19](R19.png) | 0603WAF1001T5E / C21190 | SMT Assembly | Nonpolar; both terminations aligned with intended pads. |
| [R20](R20.png) | 0603WAF1000T5E / C22775 | SMT Assembly | Nonpolar; both terminations aligned with intended pads. |
| [R21](R21.png) | 0603WAF1003T5E / C25803 | SMT Assembly | Nonpolar; both terminations aligned with intended pads. |
| [R22](R22.png) | 0603WAF2201T5E / C4190 | SMT Assembly | Nonpolar; both terminations aligned with intended pads. |
| [R25](R25.png) | 0603WAF1000T5E / C22775 | SMT Assembly | Nonpolar; both terminations aligned with intended pads. |
| [R26](R26.png) | 0603WAF1003T5E / C25803 | SMT Assembly | Nonpolar; both terminations aligned with intended pads. |
| [R27](R27.png) | 0603WAF2201T5E / C4190 | SMT Assembly | Nonpolar; both terminations aligned with intended pads. |
| [R30](R30.png) | 0603WAF1000T5E / C22775 | SMT Assembly | Nonpolar; both terminations aligned with intended pads. |
| [R31](R31.png) | 0603WAF1003T5E / C25803 | SMT Assembly | Nonpolar; both terminations aligned with intended pads. |
| [R32](R32.png) | 0603WAF2201T5E / C4190 | SMT Assembly | Nonpolar; both terminations aligned with intended pads. |
| [R35](R35.png) | 0603WAF1000T5E / C22775 | SMT Assembly | Nonpolar; both terminations aligned with intended pads. |
| [R36](R36.png) | 0603WAF1003T5E / C25803 | SMT Assembly | Nonpolar; both terminations aligned with intended pads. |
| [R37](R37.png) | 0603WAF2201T5E / C4190 | SMT Assembly | Nonpolar; both terminations aligned with intended pads. |
| [R40](R40.png) | 0603WAF1000T5E / C22775 | SMT Assembly | Nonpolar; both terminations aligned with intended pads. |
| [SW1](SW1.png) | TL3342F160QG / C2886898 | SMT Assembly | Four leads aligned; upper/lower contact-pair axis correct. |
| [SW2](SW2.png) | TL3342F160QG / C2886898 | SMT Assembly | Four leads aligned; upper/lower contact-pair axis correct. |
| [U1](U1.png) | ESP32-C3-WROOM-02-N4 / C2934560 | SMT Assembly | Antenna up; perimeter rows aligned. |
| [U2](U2.png) | AP2112K-3.3TRG1 / C51118 | SMT Assembly | Pin 1 bottom-left; three terminals on bottom; aligned. |
| [U3](U3.png) | USBLC6-2SC6 / C7519 | SMT Assembly | Pin 1 upper-left; GND left-middle / VBUS right-middle; aligned. |
| [U4](U4.png) | TPS25970LRPWR / C3662801 | SMT Assembly | Centered; upper-left marking consistent; generic body. Actual ten-terminal lands checked separately. |

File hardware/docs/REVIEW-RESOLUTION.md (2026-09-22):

# Pre-order review disposition — revision B.1

The substantive, locally actionable corrections from the [executed review](reports/preorder-review/REPORT.md) are implemented in B.1. The supported load is **four ARCTIC P14 Pro PST fans, one per board header**. Their PST expansion sockets remain unused. This preserves independent tach feedback and the existing current budget. No legacy fan, radio, universal-input or safety-rated emergency-stop requirement is added.

This is a corrected first-hardware design, not a claim that unmanufactured hardware has passed operational qualification. Production Zephyr firmware remains a separate implementation task. The old **$82.72** quote covers older inputs; B.1 has not been quoted or ordered.

## Decisions

| Review item | Engineering decision and resulting change |
|---|---|
| R-01: startup margin | Worth improving. C8 changes from 10 nF to **100 nF**, and new **R40 = 100 ohms** follows TI's recommendation for capacitors above 10 nF. The nominal output slew becomes approximately **364 ms**, reducing known reservoir charging current tenfold. Firmware must hold all PWM pins low for **750 ms after enabling**, then start individual fans sequentially, allowing each to establish tach before the next. Do not raise the 2.395 A nominal current limit. Exact standby/startup current and startup time remain first-board measurements. |
| R-02: supply/OVLO margin | The absence of an ARCTIC maximum-voltage guarantee is real missing information, not evidence that a normal 12 V supply damages the fan. The former broad 11.4–12.6 V controller target gave little nuisance-trip margin. Specify a regulated **12.0 V / at least 3 A** adapter with **11.70–12.30 V including normal ripple at the board**, and **at most 120 mV peak-to-peak ripple**. Keep R11/R12 and the existing approximately 12.91 V cutoff. This is an engineering operating target, not a newly discovered fan absolute maximum. Filtering still does not regulate DC. |
| R-03: direct tach-to-GPIO exposure | A hypothetical hidden pull-up is not proof of a fault in the P14 Pro PST. Nevertheless, the correction is inexpensive and removes an unnecessary dependency on undocumented fan internals. Replace R23/R28/R33/R38 with **Q6–Q9 common-gate MOSFET level shifters**. Gate connects to 3V3, source to MCU tach, drain to the fan tach pin. Move the pull-up to the MCU side and change it to **2.2k**. There is no direct resistor from raw tach to the MCU supply. **R19 = 1k** gives the logic rail a defined discharge/leakage load. This is voltage isolation, not galvanic isolation. |
| R-04: PWM gate-drive guarantee | Fix. Q2–Q9 use the exact **MCC SI2312-TP / C6488168**, specified at **1.8 V gate drive**, below the approximately 2.40 V conservative PWM gate bound. Pinout remains G1/S2/D3 and the SOT-23 footprint fits. The same purchased transistor serves PWM and tach, so no second transistor feeder type is introduced. Exact manufacturer datasheet and sourcing evidence are retained. |
| R-05: eFuse stencil | Fix the CAD prescription now. U4 keeps its copper lands and gets separate paste-only apertures following TI drawing **4225183/A**: two **0.28 × 1.06 mm** rounded windows per long power pad, 0.20 mm separation, and reduced rounded L-shaped corner apertures. The corner vertical arms are **0.225 × 0.650 mm**, centred at X = ±0.7125 mm; horizontal arms are **0.600 × 0.275 mm**. Corner radius 0.05 mm. Supply a **0.100 mm stencil** requirement. TI calls its example 82%/93%; the present square-corner copper polygons differ slightly in area, so verify actual exported aperture areas rather than claiming exact percentage equality. Supplier stencil/placement confirmation still happens at the assembly stage. |
| R-06: residual energy after reset | A real limitation, but not grounds for a second shutdown circuit in this wind accessory. A normally commanded stop must pull PWM low before disabling fan power. On abrupt USB loss/reset, PWM may release while the reservoir discharges; brief coasting or a twitch is allowed. Sustained powered running is not. Do not describe this as an instantaneous or safety-rated stop. The first-board test must record the actual residual behaviour. |
| R-07: thermal/transient qualification | Keep the power path and its wide traces. The revised USB/signal routing preserves the reviewed common power and USB data trace geometry. At the intended 1.4 A running load the previous modest DC-loss estimates remain applicable, but are not an enclosure temperature rating or a 3 A continuous load qualification. Keep radios disabled and measure wired/ROM/flash current and enclosure temperatures on the first boards. A complete validated fan, cable, silicon and enclosure model is unavailable; inventing one would not improve confidence. |
| R-08: firmware/watchdog | Fix the specification's overclaims. Require **500 ms valid-frame freshness**, stop-before-disable, bounded startup/fault handling, whole-system watchdog reset and no GPIO hold. CPU-only reset is insufficient. A hardware FLT-to-MCU connection or external watchdog is unnecessary for the stated product; do not claim instant fault classification. SimHub sends unchanged frames periodically at **10 Hz or faster**, with changes-only disabled. Production firmware is still not delivered by this hardware change. |
| R-09: 0.12 mm silk graphics | Cosmetic, but a cheap legitimate fabrication fix. Raise exposed graphical strokes to **at least 0.15 mm**, including local libraries. Enable 1.0 mm text height, 0.15 mm text stroke and silk gap, and 0.09 mm mask-to-neighbour-copper clearance rules. Also audit plotted graphics because KiCad text rules do not cover them. Preserve FAULT to the right of its LED, STATUS to the left, and TP5's clearance. |

## Other findings

- **Removed** R24/R29/R34/R39 and their optional USB-powered PWM pull-up routes. ARCTIC specifies internally sourced PWM signalling; the unused option added routing and a possible future back-powering mistake. No substitute pull-up is required by this fan model. Measure the normal fan/cable waveform before changing this decision.
- **Retained** the two tooling holes, four mounts, 70 × 64 mm outline, black mask and LINDESTAD silkscreen. Two tooling holes without component courtyards are a library bookkeeping issue; their actual hole/mask/copper clearances are audited.
- Legacy local-symbol footprint-filter warnings concern renamed library identifiers. They are not evidence of a wrong package. Exact pad mapping, copper, drills and assembly files are the meaningful checks.
- The missing U4 and USB-C 3D bodies remain visual omissions. Their physical lands, BOM and placements remain present. No fabricated model is used as mechanical evidence.
- RF antenna clearance is not redesigned for a wired-only controller. Radios must stay off. No arbitrary 24 V input survival, hot reverse-polarity survival or automatic OVLO recovery requirement is added.
- OVLO does not assert FLT; the red LED can remain dark during an overvoltage shutdown. The normal recovery may require disconnecting barrel power. This is stated in the firmware/specification rather than treated as a broken diagnostic.
- The obsolete stamp on the barrel-jack drawing calls for checking availability when purchasing the seven hand parts. It does not establish that the chosen part is unobtainable. Supplier-specific rotations and soldering yield cannot be certified by local CAD; retain placement confirmation and inspect the actual returned placement/stencil preview.
- Tiny factory-reflowed USB ground contacts use solid plane connections; hand-soldered connectors keep their thermal reliefs and the corrected both-face solder-mask openings. A ground stitch joins the small fan-row copper region created by rerouting.

## Electrical basis and limits

The exact P14 Pro PST manual specifies 25 kHz PWM (21–28 kHz accepted), low at most 0.8 V, sourced current at most 5 mA and open-circuit voltage at most 5.25 V. The product page lists 0 RPM below 5% PWM and recommends no more than six fans on a 2 A header. That supports a four-fan nominal load budget; it does not supply a maximum inrush waveform. [ARCTIC manual](https://support.arctic.de/en/p14-pro-pst), [ARCTIC product](https://www.arctic.de/en/P14-Pro-PST/ACFAN00314A).

MCC specifies 41.4 milliohms maximum at VGS = 1.8 V and ID = 4.3 A, at the stated 25°C datasheet condition. Applied to a 5 mA PWM load, the ohmic estimate is 0.207 mV, versus the fan's 800 mV limit. Even a deliberately severe 100× resistance sensitivity remains about 21 mV. This is substantial margin; the temperature sensitivity is not a manufacturer guarantee. The 20 V drain rating and ±8 V gate rating cover the intended signal voltages. [MCC SI2312 datasheet](https://www.mccsemi.com/pdf/Products/SI2312%28SOT-23%29.pdf).

The tach circuit uses the established common-gate translator arrangement: when the fan pulls low, the body diode initiates conduction and the channel passes the low to the source; when the fan side is high, the MCU pull-up defines its own high level. Removing USB brings the gate down and blocks a positive fan-side voltage, apart from specified leakage and capacitive transients. The signal is **not inverted**. [Nexperia/NXP AN10441](https://assets.nexperia.com/documents/application-note/AN10441.pdf).

At 3.6 V, a 2.2k ±1% pull-up sources at most 1.653 mA into a low tach output. MCC's 25°C IDSS limit of 1 µA produces at most 2.222 mV across the pull-up with the fan side held high. A separate 100 µA-per-channel leakage sensitivity produces 222.2 mV relative to the logic rail and about 0.404 V on the unpowered rail through R19; it is a stress calculation, not a hot-temperature leakage specification. R19 consumes about 3.3 mA in normal operation. Negative signal faults, ESD compliance and arbitrary miswiring are not claimed as qualified.

The known output capacitance charging sensitivity from the review decreases from about 0.409 A to about **0.041 A** when C8 increases tenfold, under the same capacitance/slew assumptions. That gives more margin during charging, while staging separates motor startup from charging. Slowing the ramp does not prove fan standby current or the eFuse's transient temperature. R40 follows the explicit TI recommendation for CdVdt above 10 nF. [TI TPS2597 datasheet, sections 7.3–7.5 and package drawings](https://www.ti.com/lit/ds/symlink/tps2597.pdf).

## Verification and release

Run `tools/export.py`, `tools/validate_b.py`, `tools/validate_b1.py` and `tools/simulate.py` with KiCad's Python. Current reports live in `reports/review-fixes/`, `reports/simulation-b1/` and the normal top-level release reports. The B.1 audit checks **every physical pad occurrence**, exact new transistor pin nets, removal of the optional pull-ups, unchanged reviewed power/USB data routing, the actual U4 paste geometry and plotted silk widths. The existing audit checks all **54** PTH solder-mask openings. Simulation output is explicitly labelled behavioural/sensitivity analysis.

Factory placement count is **63 SMT parts**; hand work remains **7 through-hole parts / 23 joints**. Two added resistors use existing Basic part types, C8 consolidates with an existing capacitor type, and Q2–Q9 share one replacement Extended transistor type. The added part material is small, but no new assembled-board total or feeder/stock guarantee is claimed without a fresh quote.

The executed review and its frozen baseline remain unchanged. Do not apply their historical PASS results to B.1 without the new checks. Supplier review and actual first-board tests remain necessary. No order, payment, stock reservation or supplier message was made during these corrections.

Final verification: ERC and full DRC/schematic parity passed with zero violations or unconnected items. All 230 numbered physical occurrences / 211 logical pins match. The plotted U4 paste has 16 verified aperture flashes, and 1,257 positive silk draw primitives passed the width check. Both tach power-sequence sensitivity cases passed: the largest simulated tach excursion above the logic rail was approximately 0.099 V. This is behavioural evidence, not a hardware guarantee.

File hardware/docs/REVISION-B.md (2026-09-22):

# Revision B — layout, sourcing and manufacturing decisions

Historical revision B document. The executed review is in [REPORT.md](reports/preorder-review/REPORT.md); current B.1 corrections and validation are in [REVIEW-RESOLUTION.md](REVIEW-RESOLUTION.md).

6 September 2026. New isolated revision; A.1 is retained unchanged by this task.

## Changes from A.1

Post-quote label/TP5 cleanup and a manufacturing-critical solder-mask correction are documented in [FINAL-CLEANUP.md](FINAL-CLEANUP.md). The current native files and Gerbers supersede those in the $82.72 draft; refresh manufacturing inputs before ordering. BOM and SMT placement counts remain unchanged.

| Item | A.1 | B |
|---|---|---|
| Board | 70 × 76 mm | 70 × 64 mm: 12 mm shorter, 15.79% less area |
| Finish appearance | Green / white | Black / white; native stackup colour and order notes |
| Branding | WIND revision label | Slanted LINDESTAD wordmark with three wind strokes |
| C6 / C9 positive-pad locations, from top-left | (11,37) / (22,43) mm | (7,26) / (6,36) mm |
| Fan-header pin-one row | y = 65 mm | y = 53 mm, same 15 mm horizontal pitch |
| Fan driver groups | Spread over approximately 51–61 mm | Repeated compact placement approximately 43.5–49.4 mm |
| Mounting-hole spacing | 63 × 69 mm | 63 × 57 mm |
| Assembly tooling holes | Supplier-added positions | Two specified 1.152 mm NPTHs, H5/H6 |
| Green status LED D3 | KT-0603G, C12624, Extended | KT-0805G, C2297, Basic; new 0805 footprint |
| Current-limit resistor R13 | 2.32 kΩ, C2933173, Extended | 2.4 kΩ, C22940, Basic |
| Nominal current limit | 2.477 A | 2.395 A |
| Module thermal-hole copper lands | 0.60 mm / 0.30 mm drill | 0.70 mm / 0.30 mm drill; 0.20 mm annular ring |

The initial 62 mm height target was relaxed to 64 mm to retain mounting-head and connector courtyard clearances. Both input connectors and the MCU/USB core keep their positions. The capacitors move in the direction indicated in the supplied image. The four driver groups retain space between packages and fan plugs; through-hole capacitor bodies retain their full physical envelopes. Ground stitching avoids the printed wordmark and labels.

## Cost decisions

D3 and R13 each eliminate an Extended type. The new live quote confirms **a $6.14 Extended-fee reduction per order**, from fifteen to thirteen types ($46.05 → $39.91). Both codes matched as Basic; no additional substitutions were needed. Stock must still be rechecked when purchasing; no parts were reserved. [Green LED](https://jlcpcb.com/partdetail/C2297), [2.4 kΩ resistor](https://jlcpcb.com/partdetail/C22940).

The current-limit change is intentional: R13 retains 1% tolerance and the same footprint. The new calculated minimum is 2.124 A with resistor temperature drift included, above the four fans' 1.4 A combined rating. Actual simultaneous startup still needs measurement. The green LED preserves its colour and cathode numbering, with an appropriate larger footprint. Its brightness at the retained low drive current is not guaranteed by the catalogue's 5 mA brightness rating.

The last **A.1** live quote was $105.13 before shipping/tax, including $21.10 green ENIG fabrication and $84.03 SMT parts/assembly. The **B live quote is $82.72**, including $5.20 black lead-free HASL fabrication and $77.52 SMT parts/assembly. Savings are **$22.41 (21.32%)**: $15.90 from fabrication/finish and $6.51 from assembly/parts. This comparison changes finish as well as the BOM; it does not attribute the full saving to shrinking the board. B remains within the original $80–105 planning allowance. [Full quote evidence](reports/jlcpcb/QUOTE.md).

| B manufacturing route, five PCBs / two assembled | USD before shipping/tax | Decision |
|---|---:|---|
| Black, lead-free HASL, Economic | **82.72 live quote, 6 September 2026** | Cost-oriented candidate; U4 process acceptance required |
| Black, ENIG, Standard with removable rails | Approximately 130–170 | Flatter finish; extra setup, stencil, panel/fixture costs; not yet panelized or quoted |

The Standard allowance uses the published single-side setup $25.56, stencil $8.21 and $1.53 feeders for all thirty MPNs, plus approximate parts and ENIG fabrication. Fixture, inspection, storage and panel charges can alter it. The handling-fee rule is conditional, not an automatic extra $14.93 to add to every estimate. Through-hole purchases, shipping, tax, power supply and enclosure are excluded from both allowances. [Current JLC fee schedule](https://jlcpcb.com/help/article/pcb-assembly-price).

## Parts retained after review

- Retain both bulk capacitors, TVS, backup fuse, reverse-polarity FET/clamp, ferrite, eFuse and USB ESD protection: deleting these changes the requested protection/filtering behaviour.
- Retain precision R11/R12. Ordinary 1% replacements would widen the overvoltage threshold unnecessarily.
- Retain BSS138 PWM transistors. The Basic 2N7002 candidate C8545 advertises on-resistance at 10 V, which is insufficient evidence of worst-case 3.3 V drive performance. A qualified low-voltage replacement could save another feeder fee later. [Candidate listing](https://jlcpcb.com/partdetail/JiangsuChangjingElec-2N7002/C8545).
- Retain BOOT and RESET. USB recovery independent of firmware is a requirement. Cheaper switches need a fresh mechanical/pin review.
- Retain the four DNP pull-up footprints. They cost no components or feeder setups and provide an edge-rate adjustment if measurements require it.
- Retain four separate PWM/tach channels. Combining fan pairs would reduce parts but lose per-fan diagnostics and flexibility.

The greatest remaining cost choice is the assembly process/finish. The current schematic already uses many Basic passives, so removing individual cheap resistors offers little saving at two assembled boards.

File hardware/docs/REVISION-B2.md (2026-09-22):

# Revision B.2 — full factory assembly

Historical: B.3 supersedes the jack, plug requirement and supplier files below. See [REVISION-B3.md](REVISION-B3.md).

7 September 2026. Supersedes the B.1 sourcing/assembly plan; the reviewed controller circuitry remains unchanged. Black 70 x 64 mm board, white LINDESTAD silkscreen, existing LED labels, mounts and tooling holes retained.

## Parts and cost decisions

| Reference | B.2 part | JLC code | Decision |
|---|---|---|---|
| J1 | XKB DC-005-5A-2.0 | C381116 | Replaces discontinued GCT jack. 5 A rating, standard 5.5 x 2.1 mm centre-positive plug. New manufacturer-derived footprint and pin numbering. |
| C6 | Panasonic EEUFR1H470 | C407950 | Exact existing 47 uF / 50 V FR part; factory THT assembly. |
| C9 | Panasonic EEUFR1E471 | C407944 | Replaces Nichicon UPW1E471MPD. 470 uF / 25 V, 10 mm diameter, 5 mm pitch, shorter 12.5 mm body. 43 milliohm impedance and 1.29 A ripple at 100 kHz. |
| J3-J6 | Molex 470531000 | C240840 | Exact existing 47053-1000 keyed fan connector, natural white; approximately $0.1775 each in the observed JLC catalogue. Black variants were not established as a stocked, documented economical assembly substitute. |
| J2 | HRO TYPE-C-31-M-12 | C165948 | Retained: approximately $0.1856, stocked, already fits the reviewed USB routing. |

Observed JLC stock: C381116 40,365 at $0.2609; C407944 154 at $0.3001; C240840 5,371 at $0.1775. Catalogue observations are unreserved and are not final checkout prices. No generic capacitor or unkeyed fan header substitutes are approved.

## Jack implementation

Manufacturer drawing `reports/full-assembly/sources/C381116.pdf` explicitly specifies a 5.5 mm OD / 2.1 mm ID mating plug with 9 mm insertion depth. Terminal 1 is centre positive; terminal 3 is the sleeve/ground; terminal 2 is the switched sleeve and is intentionally not connected. This numbering differs from the old GCT symbol and was changed in the local schematic symbol, embedded symbol and native PCB.

The drawing's top-view centres relative to terminal 1 are terminal 2: -5.9 mm along the jack axis, terminal 3: -3.0 mm axially / +4.7 mm transversely. All three plated slots are 1.0 x 3.5 mm; land sizes add a nominal 0.5 mm annular margin and both solder masks have 0.05 mm expansion. The body is 14 x 9 x 11 mm. The courtyard follows the body and protruding side terminal separately; this avoids falsely reserving a rectangular empty corner next to R10.

Terminal 1 remains at the old power entry location. All reviewed main power, USB data, protection-gate and fault tracks remain exactly identical. Four old ground spokes to the obsolete sleeve location were removed; the refilled ground planes connect the new sleeve. KiCad connectivity and DRC must pass after this change.

## Assembly and release files

Factory population is **70 components: 63 SMT plus 7 THT**, on the top side. The seven THT components have 23 solder joints per board. USB-C shell joints are part of the factory USB assembly. No separately purchased soldered components remain in this variant.

Upload `manufacturing/windpcb-revb-gerbers.zip`, `manufacturing/assembly/PCBA-BOM.csv` and `manufacturing/assembly/PCBA-CPL.csv`. The full BOM has 33 part-number groups and the CPL has 70 references. `SMT-BOM.csv` and `SMT-CPL.csv` remain partial reference exports, not the full-assembly ordering inputs. `HAND-BOM.csv` is intentionally empty except for its header.

The Gerber ZIP now includes `windpcb-F_Paste.gtp`, so the corrected B.1 U4 stencil geometry is actually supplied with the assembly upload. Preserve that paste data and request placement/stencil confirmation. The prescribed stencil thickness remains 0.100 mm. Factory process acceptance is distinct from CAD checks.

The live JLC preview revealed that the THT library origins differ from KiCad pin-one origins. PCBA-CPL.csv now places capacitors at the lead midpoint, fan headers at the four-pin row midpoint, and the XKB jack at its pad-array midpoint with the JLC-specific 0-degree rotation. The final jack body, sleeve slot, capacitor polarity and four keyed header placements were visually checked against the Gerber overlay. These are supplier-file corrections; native footprint positions and copper did not move. See MANUFACTURING.md for exact offsets.

## Power supply selection

Use a regulated, enclosed, isolated 12 V DC supply, at least 3 A, EU mains plug for Norway, centre-positive 5.5 x 2.1 mm DC plug. A 12 V 4 A or 5 A unit is also acceptable if its voltage/ripple meet the design requirements; its current rating does not force extra current into the fans. Do not select a 2.5 mm centre-hole plug or a 24 V supply.

Mean Well GST36E12-P1J is an established example of this physical format: 12 V / 3 A, EU wall adapter, P1J 5.5 x 2.1 mm centre-positive plug. It is a connector/form-factor reference, not a tested or purchased supply for this project. Its specified +/-3% voltage tolerance does not guarantee the project's tighter 11.70-12.30 V acceptance target; check the chosen unit under load and startup rather than assuming the model name establishes compliance. Ripple target is at most 120 mV peak-to-peak. The PCB filters noise and cuts off overvoltage; it does not regulate the fan rail to 12 V.

AliExpress access was blocked by browser policy. The user will source a matching supply separately; no AliExpress cart action or purchase was performed.

## Render and validation scope

J1, J2 and U4 now have local, representative dimensioned 3D bodies for a populated preview. These are visual aids, not vendor-certified clearance models. C9's original capacitor model is scaled in height to 12.5 mm. The drawing, copper, drills and courtyards remain the mechanical manufacturing authority.

The B.1 electrical audit and simulations remain applicable because the controller topology and reservoir capacitance are unchanged. Rerun ERC, full DRC with schematic parity, all physical pad net checks, both-face PTH mask checks, U4 actual Gerber paste geometry, protected-route equality and the new jack/CPL audit. Hardware startup, thermal, EMI and firmware acceptance are still required on the manufactured boards. Production Zephyr firmware is specified, not yet implemented.

The old $82.72 quote is historical and does not cover B.2. Use the separately recorded B.2 full-assembly quote when available. No order or payment is authorized.

## Sources

- [XKB JLC listing](https://jlcpcb.com/partdetail/XKBConnection-DC_005_5A_20/C381116)
- [Panasonic C9 specifications](https://industrial.panasonic.com/ww/products/pt/aluminum-cap-lead/models/EEUFR1E471)
- [Panasonic C6](https://jlcpcb.com/partdetail/PANASONIC-EEUFR1H470/C407950)
- [Molex fan header](https://jlcpcb.com/partdetail/MOLEX-470531000/C240840)
- [HRO USB-C](https://jlcpcb.com/partdetail/C165948)
- [Mean Well GST36E datasheet](https://www.meanwell.com/Upload/PDF/GST36E/GST36E-SPEC.PDF)

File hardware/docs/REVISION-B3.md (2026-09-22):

# Revision B.3 — 5.5 × 2.5 mm power input

7 September 2026. User requested the board jack match the existing TDX-1204000 supply: labelled 12 V / 4 A, centre-positive, measured approximately 5.5 mm outside / 2.5 mm inside / 10 mm barrel length. This replaces B.2's 2.1 mm input requirement. Actual adapter voltage, ripple and under-load performance are not yet measured.

## Selected component

J1 is **XKB DC-005-5A-2.5, JLC/LCSC C381115**, black, right-angle through-hole, catalogue rated 5 A / 24 V. JLC lists wave soldering and Economic/Standard assembly support. The manufacturer's drawing explicitly shows a 5.5 mm mating barrel, the 2.5 mm centre-pin option and 9 mm insertion depth. The catalogue's 6.5 mm dimension describes the jack opening, not the required plug outside diameter. A 10 mm metal barrel can leave approximately 1 mm exposed when fully inserted; enclosure clearance and actual retention require a physical fit check.

- [JLC assembly listing](https://jlcpcb.com/partdetail/XKBConnection-DC_005_5A_25/C381115)
- [Manufacturer drawing mirrored by distributor](https://img.iceasy.com/product/product/files/202107/C381115_F2190B40D933B9992A6C1A8F3C065453.pdf), retained in `reports/jack-25/sources/C381115.pdf`.

The part remains in the same cost class as B.2. [LCSC's observed small-quantity listing](https://www.lcsc.com/product-detail/C381115.html) was about $0.27 per component, but this is not a JLC PCBA checkout price or stock reservation. The subsequent B.3 browser quote is $91.80 before shipping/tax and any review surcharges; see `reports/final-checks/REPORT.md`.

## Footprint and assembly changes

New local footprint: `Wind:BarrelJack_XKB_DC-005-5A-2.5`. The drawing is a **bottom view** and must be mirrored for the board's top view. Relative to pin 1, pin 2 is 6.0 mm toward the opening; pin 3 is 3.0 mm toward the opening and 4.7 mm sideways. Pin 1 remains centre positive / VIN_RAW, pin 3 remains sleeve / GND, and pin 2 is the unused sleeve switch.

Pin 1 remains at absolute 114.2,115.0 mm and pin 3 at 111.2,119.7 mm. Pin 2 moves from 108.3,115.0 to 108.2,115.0 mm. Plated slots match the drawing: pin 1 is 3.5 × 1.0 mm in the mounted board orientation; pin 2 is 3.0 × 1.0 mm; pin 3 is 1.0 × 3.0 mm. Existing copper land sizes are retained, giving at least 0.5 mm nominal annular margin. Both-face mask expansion remains 0.05 mm. Body envelope is updated to 14.4 × 9 × 11 mm; the courtyard and representative 3D body follow it.

All tracks, vias and other component pad geometry remain unchanged. Black 70 × 64 mm board, white LINDESTAD branding and FAULT/STATUS labels are retained. The revision silkscreen reads WIND / REV B.3. The schematic, native board, local footprint, master design data, BOM and generated full PCBA BOM identify C381115 consistently. Population remains 63 SMT + 7 THT = 70 components / 33 MPN groups.

The new J1 CPL insertion point is the new pad-array midpoint: **X 11.20, Y 46.65 mm, rotation 0°**, with the existing bottom-left manufacturing origin. The subsequent C381115-specific JLC underside preview confirms registration of all three terminals with the B.3 slots; see `reports/final-checks/jlc-jack-bottom.png`. Final factory placement review remains required.

## Release and verification

Use the regenerated `manufacturing/windpcb-revb-gerbers.zip`, `manufacturing/assembly/PCBA-BOM.csv` and `PCBA-CPL.csv`. The subsequent B.3 cart draft **[historical order reference omitted]** contains these exact inputs and C381115; all 33 part groups match. The older Y2/B.2 cart remains unselected: **do not order it as B.3**. Factory process acceptance and USB-C footprint disposition remain open. No order or payment has been made. See `reports/final-checks/REPORT.md`.

Run `tools/export.py`, `validate_b.py`, `validate_b1.py`, `validate_b3.py`, then `package_release.py` with KiCad's Python. Checks cover ERC, full DRC/schematic parity, all pad nets, both-face PTH mask openings, retained protection/USB routing, unchanged full track/via geometry, new jack geometry and 70-place BOM/CPL agreement. Evidence is in `reports/jack-25/validation.json` and the current final reports. B.2 evidence remains historical. Electrical simulations do not need new models for this connector-only substitution; actual PSU and first-board tests remain outstanding.

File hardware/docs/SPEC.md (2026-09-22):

# Wind simulator controller — hardware specification

Revision B.3, 7 September 2026. Compact black PCB with LINDESTAD branding, updated factory-assembled jack and capacitors, and full assembly BOM/CPL. See REVISION-B3.md for the 5.5/2.5 mm TDX-compatible jack and REVISION-B2.md for other sourcing decisions and the previous REVIEW-RESOLUTION.md for retained electrical fixes. Design checks reduce risk; supplier process review and first-hardware qualification remain outstanding.

## Purpose and scope

One USB-connected controller operates four ARCTIC P14 Pro PST 12 V, four-wire PWM fans, one per header with their PST expansion sockets unused arranged as two funnels. SimHub supplies commands; Zephyr RTOS runs on the controller. Four independent physical PWM channels are grouped into left/right pairs in software. This project includes the native KiCad schematic and PCB, BOM, design calculations and verification records. Firmware is implemented in the separate local repository `repository root` (commit `6777767`), built against Zephyr v4.4.2 and tested in software. Its electrical interface and recovery requirements are specified here; actual-board testing remains outstanding.

The first PCB order is intended to produce usable boards, without a separate breadboard/carrier prototype. Simulation and design checks reduce risk but do not replace electrical tests on the manufactured board. No hardware performance or compliance certification is implied by a clean ERC/DRC report.

## Controller and USB

- Espressif ESP32-C3-WROOM-02-N4 module with 4 MB flash, factory assembled on the PCB. Perimeter pads and a factory-built RF/flash subsystem avoid designing a bare-chip RF circuit. See `FIRMWARE.md` for the pin map.
- Zephyr support based on the ESP32-C3 SoC, with a board-specific pin configuration. Radios disabled for normal wired operation.
- USB-C USB 2.0 full-speed data connection through the built-in USB Serial/JTAG interface. Separate 5.1 kohm CC1/CC2 pull-downs, USB ESD protection and short D+/D- routing.
- Controller powered from USB 5 V through a 3.3 V regulator; fans powered only from the barrel input. Grounds are common. No connection between barrel positive and USB VBUS.
- Physical BOOT and RESET pushbuttons. Hold BOOT, press/release RESET, then release BOOT to enter the ROM downloader. Recovery must work on a blank device and independently of Zephyr. USB-only programming must work without fan power.
- BOOT/strapping resistors and EN timing follow Espressif guidance. Native USB reserves GPIO18/19. Do not disable the ROM downloader or burn security eFuses as part of normal provisioning.
- USB suspend, enumeration current and bus-powered consumption must be validated with the firmware; regulator capacity alone is not USB power authorization.

## Fan interfaces

- Four keyed 2.54 mm PC fan headers: pin 1 GND, pin 2 switched +12 V, pin 3 tachometer, pin 4 PWM.
- Nominal fan current 0.35 A each; 1.4 A / 16.8 W combined. Design the common power path for at least 3 A and individual branches for at least 0.75 A.
- PWM frequency 25 kHz, allowed fan range 21–28 kHz. Four transistor open-drain outputs isolate MCU pins from fan pull-ups; firmware accounts for inversion. Design for at least 5 mA sink per fan, low below 0.8 V. Never apply 12 V to PWM.
- Separate tachometer inputs use Q6–Q9 common-gate SI2312-TP level shifters, with 2.2k pull-ups on the MCU side; raw fan signals have no direct resistor path to the MCU rail. Confirm actual fan tach behaviour on first hardware. Two pulses/revolution is an initial firmware assumption to verify.
- Fans specified to stop below 5% PWM. Initialization holds PWM low before enabling fan power. A hardware-default-off enable removes incoming fan power while USB/MCU is absent or resetting. Stored output energy can cause brief residual motion or a twitch; this is not an instantaneous safety stop.

## Power input, filtering and protection

- Center-positive 5.5/2.5 mm XKB DC-005-5A-2.5 barrel jack, catalogue-rated 5 A. Pin 1 is centre positive, pin 3 sleeve ground, pin 2 switched sleeve unused. External regulated 12 V / 3 A supply. Normal design input target 11.70–12.30 V including ripple, with at most 120 mV peak-to-peak ripple at the board; this is a controller/supply target, not an ARCTIC guaranteed fan tolerance.
- Reverse-polarity protection, bulk and ceramic decoupling, and provision for high-frequency filtering. Filter component ratings and damping must be checked; capacitors do not correct sustained DC error or large low-frequency ripple.
- TPS25970LRPWR electronic fuse: resistor-adjustable overvoltage cutoff, active current limiting, controlled power-on slew and separate enable. R11 = 97.6 kohm / R12 = 10 kohm, both 0.1%, give 12.912 V nominal cutoff. R13 = 2.4 kohm, 1%, gives 2.395 A nominal current limit. See `VALIDATION.md` for tolerance limits.
- Separate enable and OVLO pins; active current limiting followed by a latched shutdown if thermal protection operates. An overvoltage event has hysteretic recovery: nominal re-enable voltage is 11.836 V. Returning to exactly 12 V may require unplugging the barrel supply. Do not assume an MCU reset clears OVLO.
- A hardware pull-down keeps the fan power enable off when the MCU is unpowered or high impedance. Startup must remain off in ROM download mode.
- No full 12 V buck-boost regulation. The input includes a 3 A backup fuse, reverse P-MOSFET with a 9.1 V gate clamp, SMBJ15A TVS, 47 uF / 50 V reservoir, 3.5 A ferrite bead and ceramic bypassing. Output reservoir is 470 uF / 25 V. This is a 12 V adapter design, not a universal 24 V input; see the bounded fault assumptions in `VALIDATION.md`.
- Protection threshold adjustment is by resistor substitution, not an exposed user potentiometer.
- C8 = 100 nF and R40 = 100 ohms in series set an approximately 364 ms output ramp. Hold all PWM low for 750 ms after enabling, then start the individual motors sequentially. Current limiting is unchanged.
- Q2–Q9 are MCC SI2312-TP / C6488168, specified at 1.8 V gate drive. Q2–Q5 sink PWM; Q6–Q9 translate tach without inversion. R19 = 1k discharges the 3.3 V rail.

## Firmware contract

- USB serial integration through SimHub Custom Serial Devices initially. Serial enumeration is not automatic compatibility with SimHub's Arduino/ShakeIt protocol.
- Proposed framed ASCII command: `W,<left 0..1000>,<right 0..1000>\n`, periodically sent even when unchanged. Map each side to two PWM channels.
- Reject malformed/out-of-range commands. No fan startup on random serial data, debug logs or device connection alone.
- Start only after a valid command; hardware enforces the overvoltage cutoff. There is no MCU supply-voltage measurement or per-fan current sensing. On stale commands (500 ms initial target), disable fan power. Zero/zero also disables fan power after the PWM stop command.
- Define separate diagnostics and do not mix unsolicited Zephyr console output into the command stream. Require a whole-system watchdog reset with GPIO/peripheral hold disabled; a CPU-only reset is not sufficient.
- Final firmware must test native USB serial, hardware PWM, GPIO/tach interrupts, watchdog and boot recovery on this PCB.

## Mechanical, appearance and assembly

- 70 × 64 mm rectangle, two layers, 1.6 mm FR-4, 1 oz copper. Black solder mask on both faces, white silkscreen. Native slanted LINDESTAD lettering and three wind strokes on the top face; WIND / REV B.3 identification.
- Four 3.2 mm M3 mounting holes with 63 × 57 mm centre spacing. Two separate 1.152 mm assembly tooling holes. Exact locations, mask expansion and ordering instructions are in `MANUFACTURING.md`.
- Four keyed fan headers remain on a 15 mm pitch; their pin-one row is 53 mm from the top edge. Barrel exits left and USB-C right, at their A.1 positions. Both buttons and all plugs remain accessible.
- Move C6 positive pad to (7,26) mm and C9 to (6,36) mm from top-left. Body centres are respectively (8.25,26) and (8.5,36) mm. C6 body diameter 6.3 mm / height 11.2 mm; C9 diameter 10 mm / height 12.5 mm. These are distinct from CPL component origins.
- Factory assembly includes 70 components: 63 SMT and seven through-hole parts (J1, J3–J6, C6 and C9). No user soldering is planned. The four optional PWM pull-up footprints have been removed. Six test points and six holes require no purchased parts.
- Status D3 uses Basic KT-0805G / C2297, green 0805; fault D4 remains Basic KT-0603R / C2286, red 0603. The status brightness must be checked at the retained low-current drive. All 70 purchased components carry specific supplier codes.
- Plated minimum drill 0.3 mm. Module thermal copper lands increased to 0.7 mm for a 0.2 mm annular ring. Preserve the module antenna keepout and the segmented paste geometry.

## Manufacturing process and cost target

Black lead-free HASL / JLC Economic top-side assembly is the cost-oriented candidate, subject to the assembler accepting the U4 fine-pitch process. Black ENIG is an alternative requiring Standard assembly and an additional rail/panel design. See `MANUFACTURING.md`; neither process is approved for production by this design check.

The historical revision B JLC quote obtained through the browser on 6 September 2026 was **USD 82.72 before shipping/tax for five PCBs / two SMT assembled**, black lead-free HASL / Economic. Fabrication is $5.20 and SMT parts/assembly $77.52. The two Basic substitutions reduce Extended fees by $6.14 versus A.1. No order was placed; supplier DFM and stock at purchase remain outstanding. Through-hole purchases, power supply, fans, enclosure and firmware work are excluded. See [quote evidence](reports/jlcpcb/QUOTE.md) and `REVISION-B.md` for the comparison and alternative ENIG route.

## Verification and release

The final B cleanup moves TP5 to (46.5, 34.5) mm from the top-left and aligns FAULT right of D4 and STATUS left of D3. Soldered PTH pads require both-face mask openings with 0.05 mm expansion: 23 hand joints and four USB shell attachments. This has been corrected and independently checked in the mask Gerbers. See `FINAL-CLEANUP.md`, the executed `reports/preorder-review/REPORT.md`, and `REVIEW-RESOLUTION.md`. The quoted $82.72 upload predates these changes.

Before manufacture: clean ERC/DRC, exact pad connectivity, schematic/PCB metadata agreement, courtyard/mount/tooling-hole review, manufacturing-file origin and counts, colour and silkscreen inspection, and updated OVLO/current-limit calculations. The full verification record and limitations are in `VALIDATION.md`.

The nominal current limit is 2.395 A. Calculated IC/resistor tolerance corners are 2.134–2.661 A; including the selected resistor's 100 ppm/°C allowance over a -20 to +70 °C calculation gives 2.124–2.673 A. This calculation is not a board operating-temperature qualification or a guarantee of actual fan startup.

First hardware must test blank-device USB flashing, boot recovery, default-off power sequencing, PWM/tach behaviour, supply ripple, all-fan startup, cutoff/current limiting and thermal behaviour. Preserve the acceptance-test list in `VALIDATION.md`. Software feasibility now passes; see `reports/final-checks/REPORT.md` for the build/test evidence and remaining hardware limitations.

## References

- [ARCTIC P14 Pro PST](https://support.arctic.de/en/p14-pro-pst)
- [Espressif ESP32-C3 module](https://www.espressif.com/sites/default/files/documentation/esp32-c3-wroom-02_datasheet_en.pdf)
- [TI TPS2597](https://www.ti.com/lit/ds/symlink/tps2597.pdf)
- [Zephyr ESP32-C3](https://docs.zephyrproject.org/latest/boards/espressif/esp32c3_devkitm/doc/index.html)
- [SimHub Custom Serial Devices](https://github.com/SHWotever/SimHub/wiki/Custom-serial-devices)
- JLC process, tooling, catalogue and pricing sources are linked beside the relevant decisions in `MANUFACTURING.md` and `REVISION-B.md`.

## B.1 manufacturing correction

U4 uses TI-dimensioned split/reduced paste apertures for a 0.100 mm stencil. Copper lands are unchanged; supplier stencil and placement confirmation remains required. Graphical silkscreen is at least 0.15 mm. See [review decisions and remaining limits](REVIEW-RESOLUTION.md).

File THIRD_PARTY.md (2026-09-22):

# Third-party material

Zephyr and its dependencies are fetched separately at pinned revisions. Each retains
its upstream license; they are not vendored here. KiCad libraries are required for
standard 3D STEP models.

The project-local `hardware/libraries/Wind.pretty` footprints and symbol library include
adaptations of KiCad library material. That material remains under KiCad's **CC BY-SA
4.0 with the library exception**, including the exception for designs using the libraries.
See https://www.kicad.org/libraries/license/ and the original KiCad libraries at
https://gitlab.com/kicad/libraries. Project-specific dimensioned visual models are
representative aids, not manufacturer-certified CAD.

Supplier part numbers and manufacturer names identify compatible components; they do
not imply endorsement. Third-party datasheets, proprietary SDK binaries and account/order
screenshots are not redistributed. Python packages listed in requirements are installed
separately and retain their own licenses.

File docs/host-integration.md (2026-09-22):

# SimHub and Rig Companion

The Windows UI is maintained in [lindestad/rig-companion](https://github.com/lindestad/rig-companion).
It owns the physical USB serial port, displays fan RPM/warnings and maps vehicle speed
to left/right PWM demand. The firmware remains responsible for startup sequencing,
tach warnings, watchdog and command timeout.

## Recreate the software setup

1. Clone Rig Companion and check out the tested integration revision
   [`ae4ed97`](https://github.com/lindestad/rig-companion/commit/ae4ed97)
   (published on `wind-curves`), then follow its README to build/install with Rust:
   `git checkout ae4ed97`.
2. Install SimHub. The tested SDK/runtime is **SimHub 9.12.4**, .NET Framework 4.8.
3. Build the bridge source included in `integrations/simhub`:
   `dotnet build integrations/simhub/RigCompanion.WindBridge.csproj -c Release`.
   Pass `-p:SimHubPath=...` for a non-default SimHub installation. Proprietary SDK DLLs
   are referenced from that installation and are not redistributed here.
4. Exit SimHub and copy the built `RigCompanion.WindBridge.dll` to the SimHub directory.
   Start SimHub and enable **Rig Companion Wind Bridge** in its plugin list.
5. Connect the board with a USB data cable, open Rig Companion's Wind simulator page,
   choose channels/run mode/limits/curve, and apply. No virtual COM driver is needed.
   Do not configure SimHub to open this same physical COM port.

The bridge snapshot is maintained upstream in Rig Companion. Update both PC programs
together: protocol v2 adds game and car identity to the v1 speed-only heartbeat.
Only loopback UDP `127.0.0.1:29814` is used, at 100 ms intervals:

```json
{"version":2,"running":true,"speed_kmh":123.4,"game":"IRacing","car_id":"formulavee","car_model":"Formula Vee","car_class":"Formula Vee"}
```

The companion bundles approximate iRacing car top speeds. Full curve output occurs at
estimated top speed **minus 15 km/h**, capped by the selected maximum fan percentage.
The default curve exponent is 0.60; 1.00 is linear. The UI graph and slider edit the
curve, and a manual estimate handles unknown cars or unusual setups. Missing/stale
game data produces minimum airflow within the selected run mode. See the companion's
[`docs/wind-car-speeds.md`](https://github.com/lindestad/rig-companion/blob/ae4ed97/docs/wind-car-speeds.md)
for sources, formula, fallback rules and validation.

The paired release passed 38 Rust library tests and a test invoking the installed
SimHub SDK callback with synthetic car/speed data and receiving the actual UDP
payload. The installed bridge also passed a live COM4 check: fresh heartbeat,
controller telemetry, stopped outputs, USB release/reconnect and clean shutdown.
These checks do not validate every car estimate against an on-track maximum.

Firmware commands remain `W,left,right\n`, with each demand 0–1000. Any custom host
can implement this protocol directly; keep commands flowing every 100 ms. This source
repository contains the full board and firmware; the companion repository contains
the complete application rather than a copied, diverging second application tree.

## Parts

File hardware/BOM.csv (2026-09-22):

Reference | Value | MPN | LCSC | Footprint | Assembly | Notes
U1 | ESP32-C3-WROOM-02-N4 | ESP32-C3-WROOM-02-N4 | C2934560 | Wind:RF_Module_ESP32-C3-WROOM-02 | SMT
J2 | USB-C DATA | TYPE-C-31-M-12 | C165948 | Wind:Connector_USB_USB_C_Receptacle_HRO_TYPE-C-31-M-12 | SMT | Retained HRO TYPE-C-31-M-12: stocked economical 16-pin USB2 receptacle; shell PTH joints are part of factory assembly.
R1 | 5.1k | 0603WAF5101T5E | C23186 | Wind:Resistor_SMD_R_0603_1608Metric | SMT
R2 | 5.1k | 0603WAF5101T5E | C23186 | Wind:Resistor_SMD_R_0603_1608Metric | SMT
U3 | USBLC6-2SC6 | USBLC6-2SC6 | C7519 | Wind:Package_TO_SOT_SMD_SOT-23-6 | SMT
R3 | 22 | 0603WAF220JT5E | C23345 | Wind:Resistor_SMD_R_0603_1608Metric | SMT | Basic; 22 ohm 0603 1%, 100 mW. Reject auto-matched ET7222 IC.
R4 | 22 | 0603WAF220JT5E | C23345 | Wind:Resistor_SMD_R_0603_1608Metric | SMT | Basic; 22 ohm 0603 1%, 100 mW. Reject auto-matched ET7222 IC.
U2 | AP2112K-3.3 | AP2112K-3.3TRG1 | C51118 | Wind:Package_TO_SOT_SMD_SOT-23-5 | SMT
C1 | 1uF / 50V | CL10A105KB8NNNC | C15849 | Wind:Capacitor_SMD_C_0603_1608Metric | SMT | Basic; 0603 X5R 10%; logic decoupling, -55 to +85 C dielectric range.
C2 | 1uF / 50V | CL10A105KB8NNNC | C15849 | Wind:Capacitor_SMD_C_0603_1608Metric | SMT | Basic; 0603 X5R 10%; logic decoupling, -55 to +85 C dielectric range.
C3 | 10uF / 50V | GRM21BR61H106KE43L | C440198 | Wind:Capacitor_SMD_C_0805_2012Metric | SMT | Basic; 0805 X5R 10%; 3.3 V reservoir.
C4 | 100nF / 50V | CC0603KRX7R9BB104 | C14663 | Wind:Capacitor_SMD_C_0603_1608Metric | SMT | Basic; 0603 X7R 10%.
R5 | 10k | 0603WAF1002T5E | C25804 | Wind:Resistor_SMD_R_0603_1608Metric | SMT
C5 | 1uF / 50V | CL10A105KB8NNNC | C15849 | Wind:Capacitor_SMD_C_0603_1608Metric | SMT | Basic; 0603 X5R 10%; logic decoupling, -55 to +85 C dielectric range.
R6 | 10k | 0603WAF1002T5E | C25804 | Wind:Resistor_SMD_R_0603_1608Metric | SMT
R7 | 10k | 0603WAF1002T5E | C25804 | Wind:Resistor_SMD_R_0603_1608Metric | SMT
R8 | 10k | 0603WAF1002T5E | C25804 | Wind:Resistor_SMD_R_0603_1608Metric | SMT
SW1 | BOOT | TL3342F160QG | C2886898 | Wind:Button_Switch_SMD_SW_SPST_TL3342 | SMT | Original E-Switch SMD switch is stocked; do not use through-hole TL1220 RESET auto-match.
SW2 | RESET | TL3342F160QG | C2886898 | Wind:Button_Switch_SMD_SW_SPST_TL3342 | SMT | Original E-Switch SMD switch is stocked; do not use through-hole TL1220 RESET auto-match.
R9 | 1k | 0603WAF1001T5E | C21190 | Wind:Resistor_SMD_R_0603_1608Metric | SMT
D3 | STATUS GREEN | KT-0805G | C2297 | Wind:LED_SMD_LED_0805_2012Metric | SMT | Basic green 0805; pad 1 cathode; brightness at low current requires first-board check
J1 | 12V / CENTER + | DC-005-5A-2.5 | C381115 | Wind:BarrelJack_XKB_DC-005-5A-2.5 | THT | XKB 5A; 5.5/2.5mm centre-positive plug, 9mm insertion. Pin 1 centre, pin 3 sleeve, pin 2 switched sleeve NC. Bottom-view drawing mirrored to top: pin2 axial -6mm, pin3 axial -3mm / transverse +4.7mm.
F1 | 3A / 32V | 0466003.NRHF | C14165 | Wind:Fuse_Fuse_1206_3216Metric | SMT | Littelfuse 466 1206 fast 3A 32V; input backup fuse, not calibrated fan current limiter
Q1 | AO3401A | AO3401A | C15127 | Wind:Package_TO_SOT_SMD_SOT-23 | SMT | Reverse protection: drain faces input; source faces load
R10 | 4.7k | 0603WAF4701T5E | C23162 | Wind:Resistor_SMD_R_0603_1608Metric | SMT | Biases 9.1V reverse-FET gate clamp
D1 | BZT52C9V1 | BZT52C9V1-7-F | C260913 | Wind:Diode_SMD_D_SOD-123 | SMT | 9.1V gate-source clamp; AO3401A absolute Vgs is 12V
D2 | SMBJ15A TVS | SMBJ15A | C83846 | Wind:Diode_SMD_D_SMB | SMT | Littelfuse; unidirectional SMB/DO-214AA, 15 V standoff, 24.4 V rated clamp; stocked exact electrical type.
C6 | 47uF / 50V | EEUFR1H470 | C407950 | Wind:Capacitor_THT_CP_Radial_D6.3mm_P2.50mm | THT | Panasonic FR: 6.3mm diameter, 11.2mm body, 2.5mm lead spacing
FB1 | 120R@100MHz / 3.5A | BLM31PG121SN1L | C85841 | Wind:Inductor_SMD_L_1206_3216Metric | SMT
C7 | 1uF / 50V | CL21B105KBFNNNE | C28323 | Wind:Capacitor_SMD_C_0805_2012Metric | SMT | Basic; 0805 X7R 50 V 10%.
U4 | TPS25970LRPWR | TPS25970LRPWR | C3662801 | Wind:TPS25970_RPW0010A_2x2mm | SMT
R11 | 97.6k 0.1% | RT0603BRE0797K6L | C862326 | Wind:Resistor_SMD_R_0603_1608Metric | SMT | Stock replacement for C861608 shortfall; 97.6k 0.1%, 50 ppm/C (previously 25 ppm/C). See drift calculation.
R12 | 10k 0.1% | RT0603BRD0710KL | C95204 | Wind:Resistor_SMD_R_0603_1608Metric | SMT | Retain 10k 0.1%, 25 ppm/C for OVLO divider.
R13 | 2.4k 1% | 0603WAF2401T5E | C22940 | Wind:Resistor_SMD_R_0603_1608Metric | SMT | Basic ILIM resistor: nominal 2.395 A; 1%, 100 ppm/C
C8 | 100nF / 50V | CC0603KRX7R9BB104 | C14663 | Wind:Capacitor_SMD_C_0603_1608Metric | SMT | 100 nF X7R; ~0.36 s nominal 12 V slew; firmware waits 750 ms with PWM stopped
R14 | 1k | 0603WAF1001T5E | C21190 | Wind:Resistor_SMD_R_0603_1608Metric | SMT
R15 | 10k | 0603WAF1002T5E | C25804 | Wind:Resistor_SMD_R_0603_1608Metric | SMT
C11 | 100nF / 50V | CC0603KRX7R9BB104 | C14663 | Wind:Capacitor_SMD_C_0603_1608Metric | SMT | Basic; 0603 X7R 10%.
C9 | 470uF / 25V | EEUFR1E471 | C407944 | Wind:Capacitor_THT_CP_Radial_D10.0mm_P5.00mm | THT | Panasonic FR 470uF 25V: D10 x H12.5mm, pitch 5mm; impedance 43mohm, ripple 1.29A at 100kHz; same capacitance and voltage.
C10 | 1uF / 50V | CL21B105KBFNNNE | C28323 | Wind:Capacitor_SMD_C_0805_2012Metric | SMT | Basic; 0805 X7R 50 V 10%.
R16 | 4.7k | 0603WAF4701T5E | C23162 | Wind:Resistor_SMD_R_0603_1608Metric | SMT | Output discharge: ~2.2 s RC with 470uF, not an instantaneous discharge
R17 | 10k | 0603WAF1002T5E | C25804 | Wind:Resistor_SMD_R_0603_1608Metric | SMT
D4 | FAULT RED | KT-0603R | C2286 | Wind:LED_SMD_LED_0603_1608Metric | SMT | KENTO Basic red 0603; replaces Extended LED to avoid one feeder fee. Preserve pad 1 cathode.
R18 | 2.2k | 0603WAF2201T5E | C4190 | Wind:Resistor_SMD_R_0603_1608Metric | SMT
J3 | L1 | 470531000 | C240840 | Wind:Connector_FanPinHeader_1x04_P2.54mm_Vertical | THT | Genuine Molex 47053-1000, natural white, factory wave soldering; exact existing keyed fan footprint.
Q2 | SI2312-TP | SI2312-TP | C6488168 | Wind:Package_TO_SOT_SMD_SOT-23 | SMT | MCC exact part; G1/S2/D3; RDS(on) specified at VGS=1.8 V
R20 | 100 | 0603WAF1000T5E | C22775 | Wind:Resistor_SMD_R_0603_1608Metric | SMT | Basic; 100 ohm 0603 1%, 100 mW.
R21 | 100k | 0603WAF1003T5E | C25803 | Wind:Resistor_SMD_R_0603_1608Metric | SMT
R22 | 2.2k | 0603WAF2201T5E | C4190 | Wind:Resistor_SMD_R_0603_1608Metric | SMT | MCU-side tach pull-up; Q6-Q9 separate raw fan voltage
J4 | L2 | 470531000 | C240840 | Wind:Connector_FanPinHeader_1x04_P2.54mm_Vertical | THT | Genuine Molex 47053-1000, natural white, factory wave soldering; exact existing keyed fan footprint.
Q3 | SI2312-TP | SI2312-TP | C6488168 | Wind:Package_TO_SOT_SMD_SOT-23 | SMT | MCC exact part; G1/S2/D3; RDS(on) specified at VGS=1.8 V
R25 | 100 | 0603WAF1000T5E | C22775 | Wind:Resistor_SMD_R_0603_1608Metric | SMT | Basic; 100 ohm 0603 1%, 100 mW.
R26 | 100k | 0603WAF1003T5E | C25803 | Wind:Resistor_SMD_R_0603_1608Metric | SMT
R27 | 2.2k | 0603WAF2201T5E | C4190 | Wind:Resistor_SMD_R_0603_1608Metric | SMT | MCU-side tach pull-up; Q6-Q9 separate raw fan voltage
J5 | R1 | 470531000 | C240840 | Wind:Connector_FanPinHeader_1x04_P2.54mm_Vertical | THT | Genuine Molex 47053-1000, natural white, factory wave soldering; exact existing keyed fan footprint.
Q4 | SI2312-TP | SI2312-TP | C6488168 | Wind:Package_TO_SOT_SMD_SOT-23 | SMT | MCC exact part; G1/S2/D3; RDS(on) specified at VGS=1.8 V
R30 | 100 | 0603WAF1000T5E | C22775 | Wind:Resistor_SMD_R_0603_1608Metric | SMT | Basic; 100 ohm 0603 1%, 100 mW.
R31 | 100k | 0603WAF1003T5E | C25803 | Wind:Resistor_SMD_R_0603_1608Metric | SMT
R32 | 2.2k | 0603WAF2201T5E | C4190 | Wind:Resistor_SMD_R_0603_1608Metric | SMT | MCU-side tach pull-up; Q6-Q9 separate raw fan voltage
J6 | R2 | 470531000 | C240840 | Wind:Connector_FanPinHeader_1x04_P2.54mm_Vertical | THT | Genuine Molex 47053-1000, natural white, factory wave soldering; exact existing keyed fan footprint.
Q5 | SI2312-TP | SI2312-TP | C6488168 | Wind:Package_TO_SOT_SMD_SOT-23 | SMT | MCC exact part; G1/S2/D3; RDS(on) specified at VGS=1.8 V
R35 | 100 | 0603WAF1000T5E | C22775 | Wind:Resistor_SMD_R_0603_1608Metric | SMT | Basic; 100 ohm 0603 1%, 100 mW.
R36 | 100k | 0603WAF1003T5E | C25803 | Wind:Resistor_SMD_R_0603_1608Metric | SMT
R37 | 2.2k | 0603WAF2201T5E | C4190 | Wind:Resistor_SMD_R_0603_1608Metric | SMT | MCU-side tach pull-up; Q6-Q9 separate raw fan voltage
TP1 | GND | PCB test point |  | Wind:TestPoint_TestPoint_Pad_D1.5mm | PCB
TP2 | +3V3 | PCB test point |  | Wind:TestPoint_TestPoint_Pad_D1.5mm | PCB
TP3 | FAN_12V | PCB test point |  | Wind:TestPoint_TestPoint_Pad_D1.5mm | PCB
TP4 | VIN_FILTERED | PCB test point |  | Wind:TestPoint_TestPoint_Pad_D1.5mm | PCB
TP5 | FAULT_N | PCB test point |  | Wind:TestPoint_TestPoint_Pad_D1.5mm | PCB
TP6 | EFUSE_EN | PCB test point |  | Wind:TestPoint_TestPoint_Pad_D1.5mm | PCB
Q6 | SI2312-TP | SI2312-TP | C6488168 | Wind:Package_TO_SOT_SMD_SOT-23 | SMT | Common-gate tach level shifter: gate 3V3, source MCU, drain fan; body diode points MCU to fan
Q7 | SI2312-TP | SI2312-TP | C6488168 | Wind:Package_TO_SOT_SMD_SOT-23 | SMT | Common-gate tach level shifter: gate 3V3, source MCU, drain fan; body diode points MCU to fan
Q8 | SI2312-TP | SI2312-TP | C6488168 | Wind:Package_TO_SOT_SMD_SOT-23 | SMT | Common-gate tach level shifter: gate 3V3, source MCU, drain fan; body diode points MCU to fan
Q9 | SI2312-TP | SI2312-TP | C6488168 | Wind:Package_TO_SOT_SMD_SOT-23 | SMT | Common-gate tach level shifter: gate 3V3, source MCU, drain fan; body diode points MCU to fan
R19 | 1k | 0603WAF1001T5E | C21190 | Wind:Resistor_SMD_R_0603_1608Metric | SMT | 3.3 mA logic-rail bleed; finite load during USB removal and tach leakage
R40 | 100 | 0603WAF1000T5E | C22775 | Wind:Resistor_SMD_R_0603_1608Metric | SMT | TI 100 ohm series damping for C8 > 10 nF

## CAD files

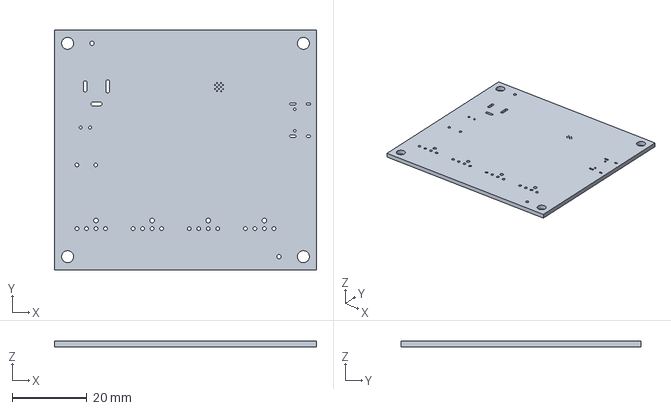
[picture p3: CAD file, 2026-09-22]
hardware/manufacturing/board-only.step
70.0 x 64.0 x 1.51 mm

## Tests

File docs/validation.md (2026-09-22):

# Current functional status — 22 September 2026

The assembled board was flashed through native USB. One-fan warning behaviour and powered R1/R2 operation were exercised; user confirmed normal start/stop and good airflow. The RPM telemetry firmware was flashed successfully with 12 V attached, and the Rig Companion/SimHub bridge passed a stopped-output hardware smoke test. User subsequently confirmed the integrated application works. At 100% demand, reported speeds were roughly 2,470/2,410 RPM. Independent voltage, current, temperature, PWM timing and calibrated RPM measurements remain unperformed.

The chronological notes below retain the limits of each test when it was performed; later entries supersede earlier “pending” statements.

# Pre-order firmware verification

## 22 September 2026 update: optional fans and USB warnings

The current firmware supersedes the original tach-fault shutdown behaviour described in the historical pre-order results below. Startup without tach and tach loss now set per-header warnings while all commanded outputs continue. The next header starts after either confirmed tach plus 500 ms, or a 2 s timeout. Zero through four connected fans are supported. Command loss, RX-budget exhaustion, actuator failure and the existing hardware power protections are unchanged.

- 25 actual-C host tests PASS, covering all 16 populations of connected fans; no-tach startup progression; one running fan losing tach; three-edge warning recovery; side stop/restart; timer wrap; status encoding; command expiry and hard faults while warnings are present. The original parser/random-traffic/output tests remain included.
- Zephyr target build PASS, 43 configuration/pin/image checks PASS; image size 133,876 bytes. Added interrupt-driven USB TX so status reports do not use blocking character writes in the control loop.
- Flashed on COM4 using the generated Zephyr runner; esptool verified the flash hash (`reports/warning-firmware-flash.log`). No eFuse/security settings were changed.
- Actual-board USB test PASS with **12 V physically disconnected**: repeated OFF reports, precharge, sequential warning masks 1/3/7/F while remaining ACTIVE, command-timeout state, then explicit OFF. Evidence: `reports/warning-usb-smoke.json`; rerun with `tests/usb_smoke.py --port COM4 --no-fan-power` only after physically disconnecting the barrel supply. This tests actual application execution/USB but cannot prove fan voltage, motor rotation or electrical timing.
- The complete stop-before-flash helper was exercised against the board: repeated OFF snapshots for two seconds, successful hash-verified flashing, automatic reset, and OFF reports afterwards (`reports/stop-first-flash.log`). OFF telemetry describes requested outputs; it cannot measure whether the capacitors are discharged. This test used USB only; flashing with 12 V attached has not been physically tested.
- Before this update, the user confirmed that the original firmware started and stopped a single L1 fan during a two-second command test. A sustained two-fan test of the new warning behaviour is still pending.

Remaining checks include real tach warning/recovery with powered motors, both sides, measured output timing and watchdog reset, prolonged USB TX backpressure, current/thermal behaviour and SimHub end-to-end integration. A successful USB status test does not close those items. Routine flashing with the normal 12 V supply connected does not introduce a separate electrical damage or permanent-bricking mechanism; USB supplies the MCU, and ROM download recovery remains enabled. Supply faults and USB interruption are separate from fan motion; an interrupted write normally needs reflashing.

### RPM integration update, 22 September

Added one-second T2 telemetry (per-header estimated RPM/output, uptime, command counters). RPM computation uses actual window duration and 64-bit arithmetic; output formatting is bounded. The existing S1 status frames are retained and the stop-first flash helper ignores T2 records. 26 host tests and 43 target checks PASS. Firmware was hash-verified when flashed with 12 V connected, and actual COM4 idle telemetry returned valid 15-field T2 frames (`reports/rpm-usb-idle.json`). Rig Companion's live smoke test subsequently passed telemetry, SimHub heartbeat, zero requested output, release/reconnect and shutdown. This update does not claim independently measured RPM accuracy or a powered vehicle-speed test.

## Historical pre-order results

7 September 2026, WindPCB B.3. **Software feasibility checks PASS.** These establish a buildable implementation for the existing pins, not physical operation of unmanufactured hardware.

- Clean target build: Zephyr v4.4.2, commit `dccb09599635bdff17633fa7e9dab014b91dce90`, SDK 1.0.1 / RISC-V GCC 14.3.0, Python 3.12.10, west 1.5.0, esptool 5.4.0.
- 42 generated configuration/pin-map/image checks pass. Exact ESP32-C3-WROOM-02-N4 and 4 MiB flash; native USB Serial/JTAG; UART0/1 and radios disabled; PWM channels 0–3 on GPIO4–7 at 25 kHz; tach GPIO0/1/3/20, enable GPIO10, status GPIO21. Pin assignments cross-checked against B.3 master CAD data.
- 19 tests execute the actual control and output C sources using host GCC with warnings treated as errors. They include 20,000 cases checked against an independent parser oracle and 100,000 seeded random events.
- Behavioural checks cover cold boot, noise, partial/overlong frames, 500 ms freshness, timer wrap, 750 ms precharge, 250 ms kicks, at least 500 ms between fan starts, three new tach edges before advancing, side cancellation/rejoining, startup/stall faults, explicit rearm, output polarity and PWM-stop-before-power-disable ordering.
- Output failure injection confirms the power-disable request occurs immediately after a failed PWM write and no subsequent enable request occurs in that transaction.
- Flash image is 133,780 bytes (about 3.19% of the usable 4 MiB flash region). The generated memory regions overlap physical IRAM/DRAM backing; their percentages must not be summed as independent memory pools.

The prior review's development snapshot and prospective firmware were not reused as production proof. The new custom board definition selects the actual WROOM module and carries no development-board UART pin ownership. Zephyr's LEDC driver was inspected: the DTS `inverted` child property selects the initial stopped output level, while runtime flags overwrite that state. Application requests use normal polarity and explicit inverted gate duty exactly once. The watchdog driver maps RESET_SOC to system reset and uses consecutive interrupt/reset stages; actual pin release and latency remain hardware checks.

Dependency installation fetched all default-active Zephyr manifest modules, all Espressif blobs and both Zephyr/module Python requirements. Optional unrelated module groups are not enabled. The existing complete SDK 1.0.1 matches this release's SDK_VERSION, so it was reused. `west update` ultimately passed and `pip check` found no broken dependencies. A shallow-fetch attempt omitted some pinned commits; fetching those exact manifest revisions and rerunning west resolved this without changing release pins. Other workspaces were not updated.

## Remaining physical checks

Blank-flash ROM USB enumeration and BOOT/RESET recovery; native USB command transport on Windows; real PWM frequency/voltage, tach pulse count and filtering; actual fan standby/startup current and ramp behaviour; low-speed tach stability; watchdog reset effects; output timing under USB load; supply ripple/voltage and enclosure temperatures. The user has no PSU measurement equipment; its label/fit are accepted as a purchasing assumption, not a measured PASS.

No hardware schematic or routing change was required by this firmware work. SimHub's intended Custom Serial Devices frame is documented, but the real SimHub-to-board connection cannot be exercised without the board. The source, tests and reproducible scripts are local Git deliverables; no firmware was flashed and no remote repository was created.

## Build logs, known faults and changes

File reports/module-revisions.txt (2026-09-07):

manifest: N/A
acpica: 8d24867bc9c9d81c81eeac59391cda59333affd4
cmsis: 512cc7e895e8491696b61f7ba8066b4a182569b8
cmsis-dsp: 97512610ec92058f0119450b9e743eeb7e95b5c8
cmsis-nn: d20117c9e88cf9018d6fa06744dddac700c3e3a1
cmsis_6: 30a859f44ef8ab4dc8f84b03ed586fd16ccf9d74
dhara: 6f163ca05e174b168b4d148160b50eeaeeb561fc
edtt: c282625e694f0b53ea53e13231ea6d2f49411768
fatfs: f4ead3bf4a6dab3a07d7b5f5315795c073db568d
hal_adi: c8aa8d545635a5821045ab500c70b878bd55f15d
hal_afbr: 1abf6947457380934e27f92508ec5532ddedfc6d
hal_ambiq: 21565be7baa02f03d27a734bf9939c0dcb3cfec9
hal_atmel: 8cd575049f04131e333558072484bfc6334c19c4
hal_bouffalolab: c71e1197e7e9e0fd7be801844e09533c030b56a9
hal_espressif: f07465053c0f24aa254d9fdfd559f06879221073
hal_ethos_u: 03567073fe2b9802c0bd73f9534da6f8a03924d1
hal_gigadevice: ee0e31302c21b2a465dc303b3ced8c606c2167c8
hal_infineon: 3ae25facf70c296145f6e12aa10b4810d49c2b33
hal_intel: 2ddab7fe5bfe85c7af8b87a490c4a0e560dc1078
hal_microchip: 86f3ea6b389d860332bd81ae8b97543def619395
hal_nordic: 44fd3d44b15cb75f80a25b4679f91d2787e28664
hal_nuvoton: fe26f3a5b3b85fb6b61cc3f744f195e3ab391194
hal_nxp: 7554bc0f6f6c284972eba7b2c17b16fbb9cc0ad0
hal_openisa: eabd530a64d71de91d907bad257cd61aacf607bc
hal_quicklogic: bad894440fe72c814864798c8e3a76d13edffb6c
hal_realtek: 84a7fd556d95a411ee3cbf4ed29478eced58fb35
hal_renesas: 06282060fa20cbd21d4ebbc7d46a1fc9533fd24e
hal_rpi_pico: 562b41e10a1d8b1a761b253b107c5c6a84cf4535
hal_sifli: 86fa0e9433fda1a760e0077c19b8407ecceea2f9
hal_silabs: f5201210afa1319ed8dd8dbe21682bcb63b25771
hal_st: 7a792882847223c72944791e0c48eed6101e6569
hal_stm32: fc11896dd39cfca37bf9b4aeaaa2df8861b81875
hal_tdk: fa54cb65535b0ed69564423c9e0bf4e7ee47dcb1
hal_telink: 4226c7fc17d5a34e557d026d428fc766191a0800
hal_ti: afbcfffd393be03ca2c9b41f9ce8d94a4c2f2fbd
hal_wch: dd3855ea624b05de7e6e95584789615d2058a0f3
hal_wurthelektronik: 7c1297ea071d03289112eb24e789c89c7095c0a2
hal_xtensa: 0495a1afd300b644d3ec8dd2c3bd11007e69a892
hostap: aa993679725360c1e370c9695960c6730cb07e8b
liblc3: 48bbd3eacd36e99a57317a0a4867002e0b09e183
libmctp: b97860e78998551af99931ece149eeffc538bdb1
libmetal: 66e084293b2a7ced5a73fbd247deddba8915883a
libsbc: 8e1beda02acb8972e29e6edbb423f7cafe16e445
littlefs: 8f5ca347843363882619d8f96c00d8dbd88a8e79
lora-basics-modem: a8ddc544043e72807cf7db532478e1dda734ae7c
loramac-node: fb00b383072518c918e2258b0916c996f2d4eebe
lvgl: 85aa60d18b3d5e5588d7b247abf90198f07c8a63
mbedtls: a3e190fe44c78d1ba67f55979e1257328cc7d0d8
mbedtls-3.6: a00e23de17b6b0a0de28e180cb186da6f0008836
mcuboot: 6d3b3d2c38ab20c242e5b9abb04d050086383eb2
mipi-sys-t: 5a9d6055b62edc54566d6d0034d9daec91749b98
mldsa-native: 3fc19982839305d305071f0de0c540bc9c9bea8a
nanopb: 5499fd4c9a478f8139eeb07a82c3b4468d6067f7
net-tools: 64d7acc661ae2772282570f21beab85d02f2f35c
nrf_hw_models: 158b9710d6e10c57b2c623f8f4178f0bbc85c23f
nrf_wifi: cebea8e27ceb91a7d4580d17db65f93669befe72
open-amp: 5efe7974f9546582e99f5a842a816ea4b65f5227
openthread: e4d97681c53ec1cc34af1404ad2960adda4ba691
percepio: f9159fe3c79578e8d90c8593e83f9862d9b8962c
picolibc: 01254932e8e81085817ed61fd858648584ffe37c
psa-arch-tests: 6e8219237435112df33bbcf37b7f5657fcfb9cff
segger: 50892fdbcf2f570e67baa72b8894a66b16946f72
tf-m-tests: cde5b6ed540d3ff5a09564fded6b39b0a70ad3bf
tf-psa-crypto: dc575a2ddcc8cb16275d24c42a52eaf79ebe2231
trusted-firmware-a: 4aef38a5bf03edfa615c1f8af5a49e7065f9fb3f
trusted-firmware-m: 9a4cb1a280b63a5e66bd469e82eb75f2b3e05a78
uoscore-uedhoc: dc0ab6345450668de3f9597320a48c5a2d409bb6
zcbor: 9164bd18dcd88ff9d9ef98279501fc1093571017

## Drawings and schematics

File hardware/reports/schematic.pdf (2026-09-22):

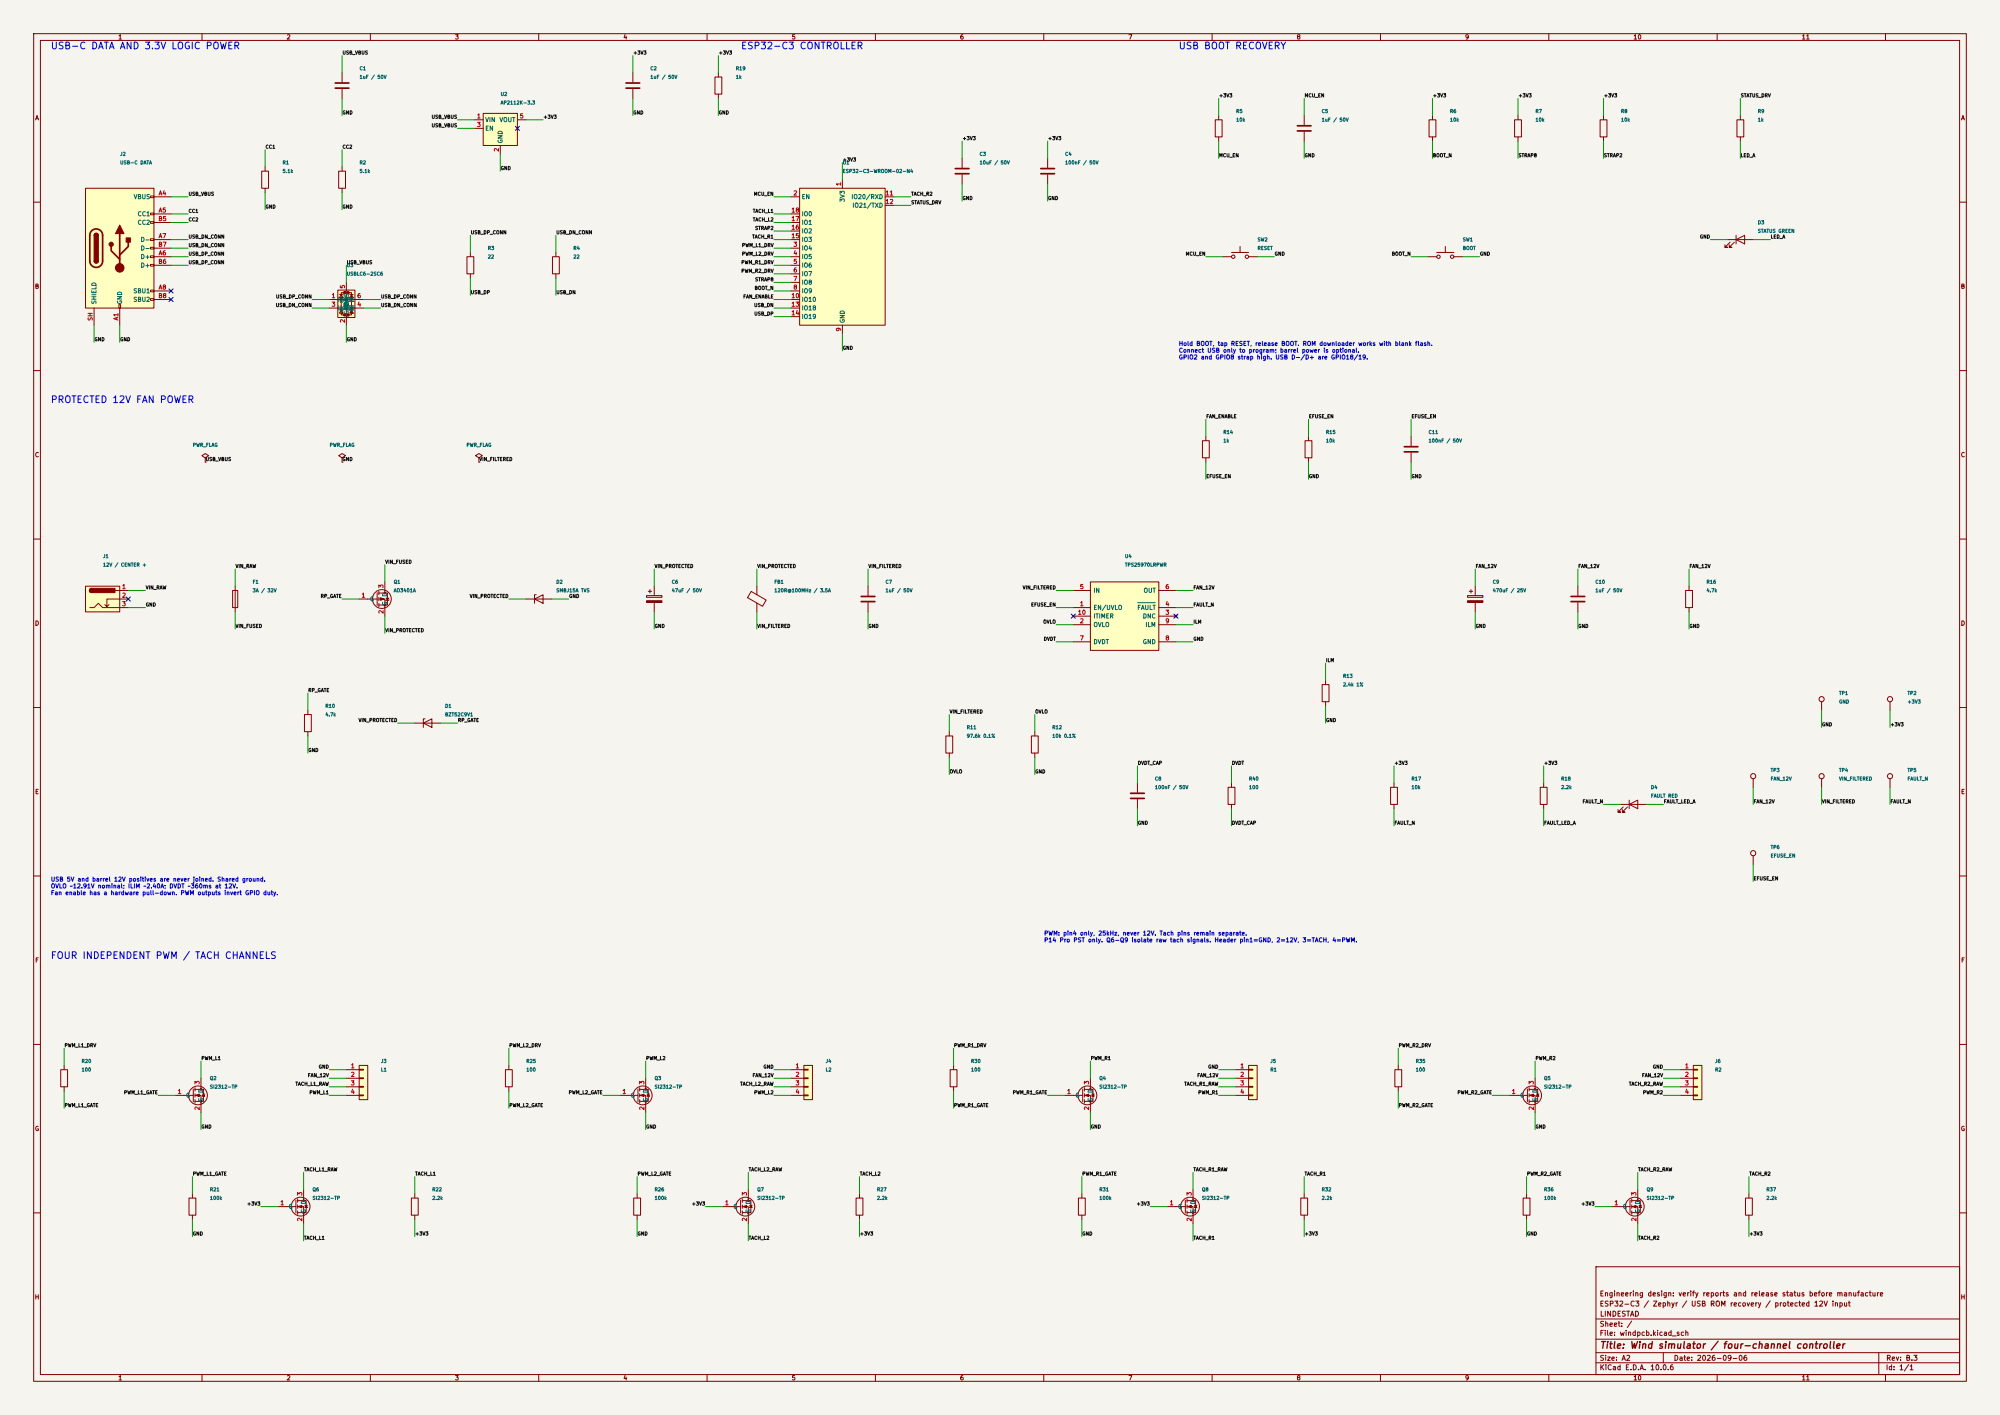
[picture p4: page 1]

Hold BOOT, tap RESET, release BOOT. ROM downloader works with blank flash. Connect USB only to program; barrel power is optional. GPIO2 and GPIO8 strap high. USB D-/D+ are GPIO18/19.

VIN_FILTERED FOUR INDEPENDENT PWM / TACH CHANNELS

USB 5V and barrel 12V positives are never joined. Shared ground. OVLO ~12.91V nominal; ILIM ~2.40A; DVDT ~360ms at 12V. Fan enable has a hardware pull-down. PWM outputs invert GPIO duty.

PWM: pin4 only, 25kHz, never 12V. Tach pins remain separate. P14 Pro PST only. Q6-Q9 isolate raw tach signals. Header pin1=GND, 2=12V, 3=TACH, 4=PWM.

Engineering design: verify reports and release status before manufacture
ESP32-C3 / Zephyr / USB ROM recovery / protected 12V input
LINDESTAD
Sheet: /
File: windpcb.kicad_sch
Title: Wind simulator / four-channel controller

Size: A2 | Rev: B.3
KiCad E.D.A. 10.0.6 | Id: 1/1

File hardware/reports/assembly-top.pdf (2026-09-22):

R19

1919

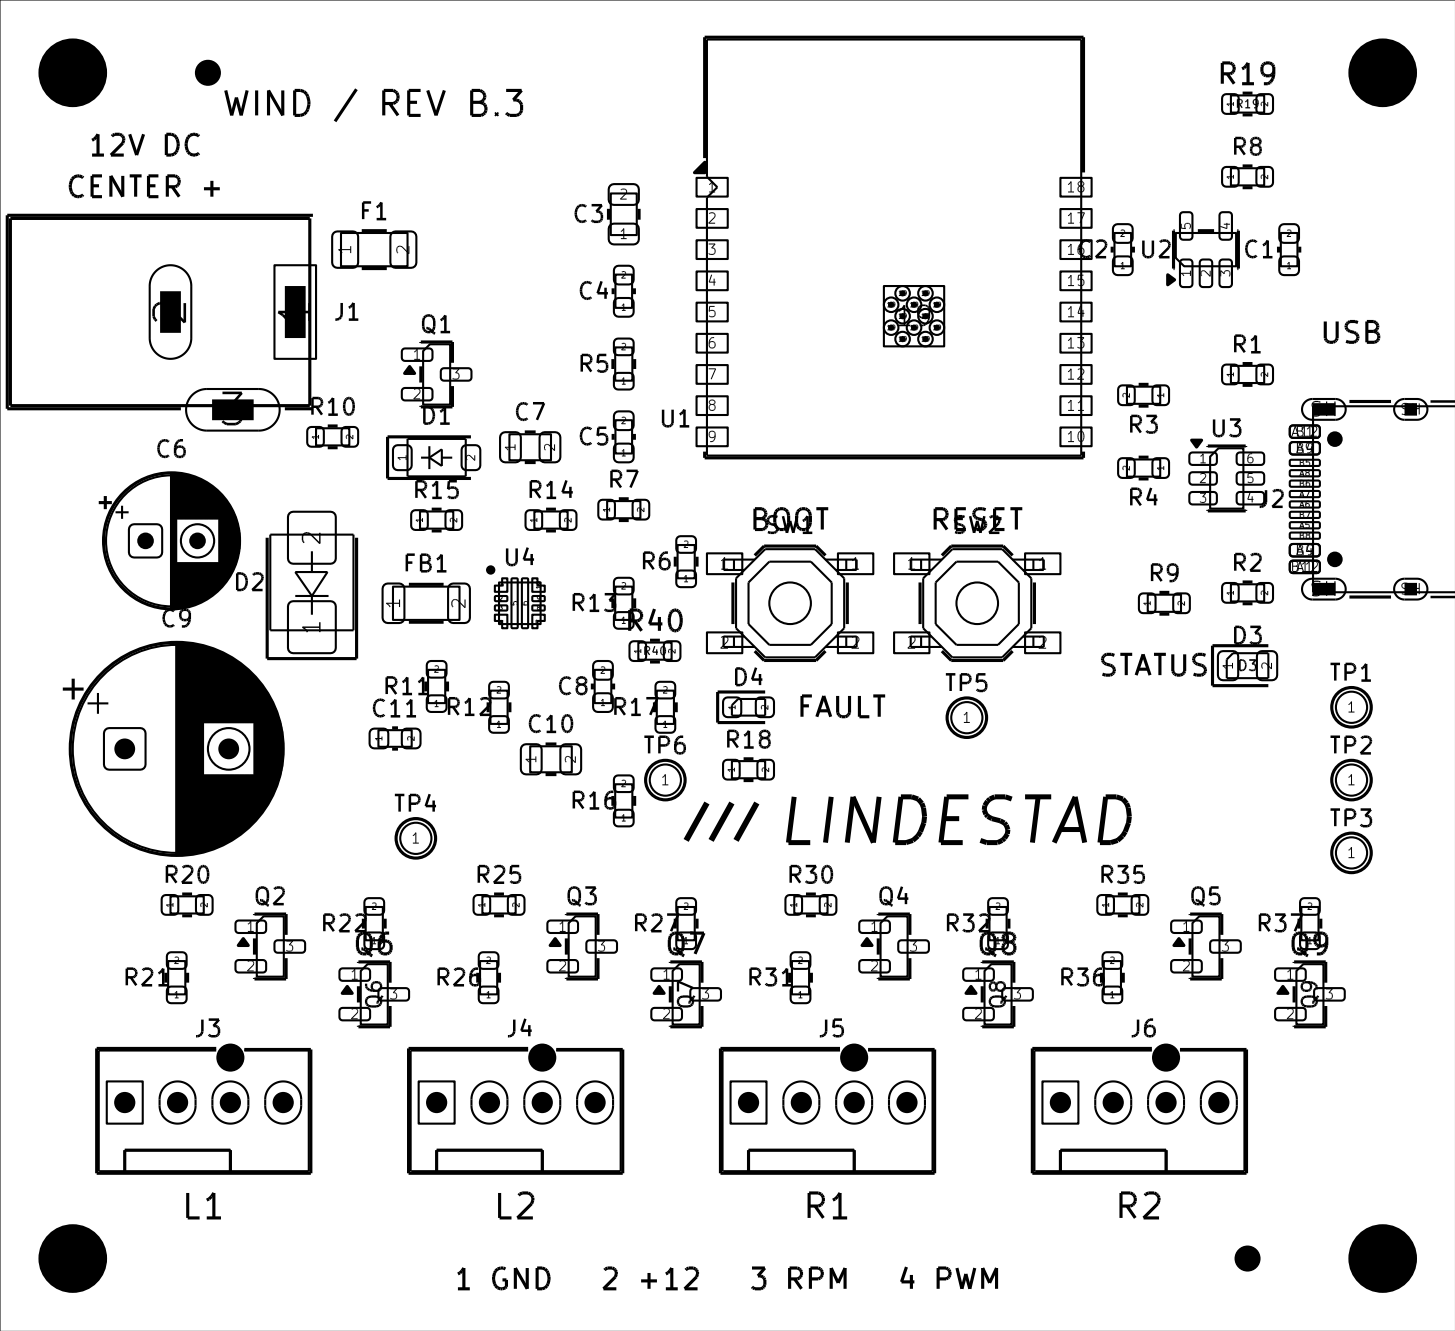
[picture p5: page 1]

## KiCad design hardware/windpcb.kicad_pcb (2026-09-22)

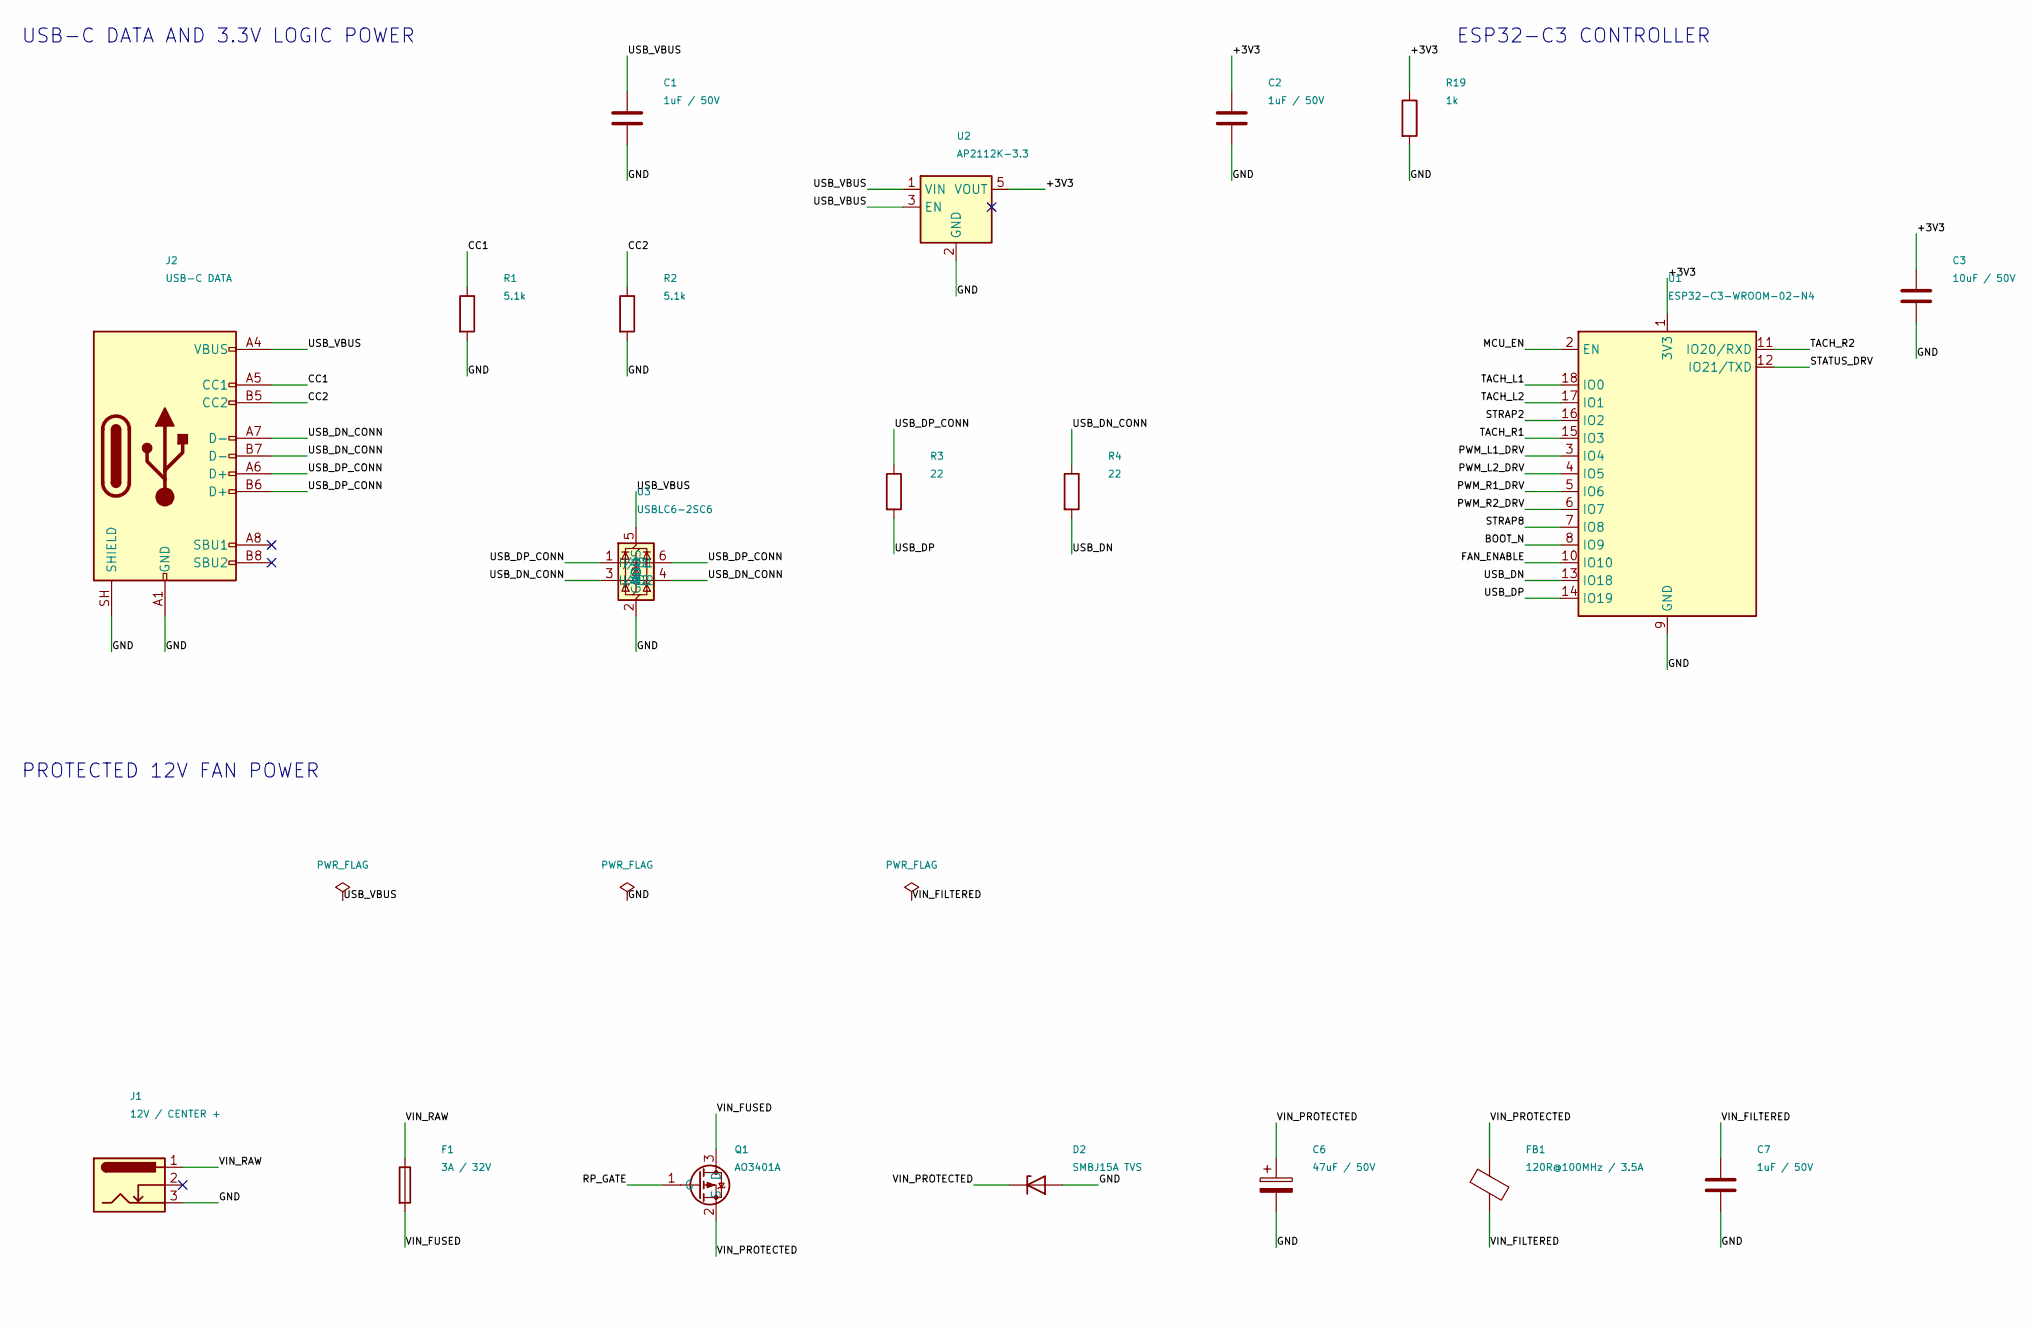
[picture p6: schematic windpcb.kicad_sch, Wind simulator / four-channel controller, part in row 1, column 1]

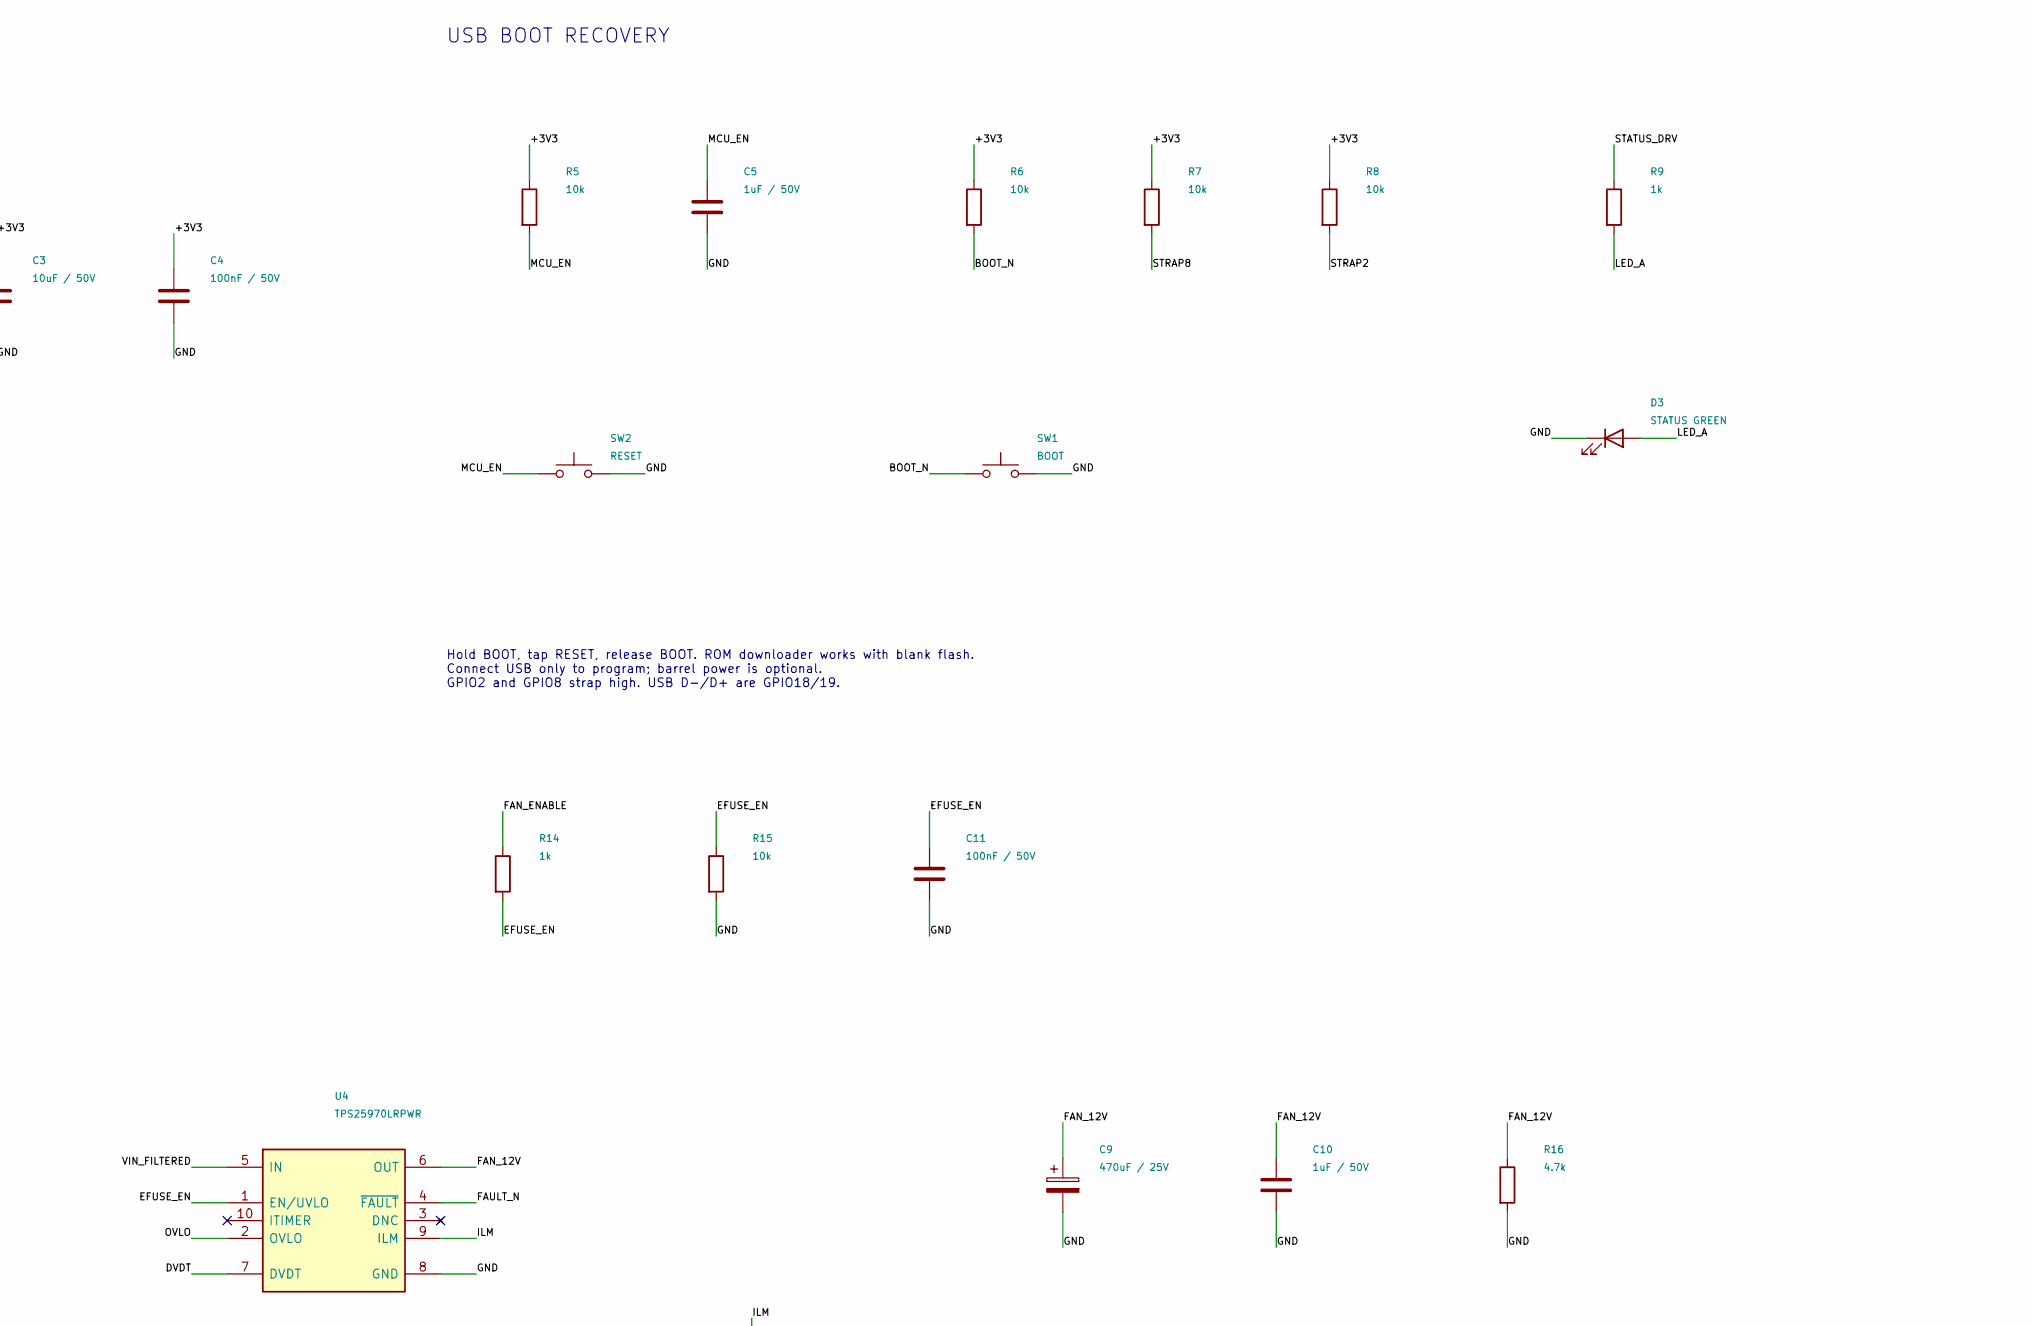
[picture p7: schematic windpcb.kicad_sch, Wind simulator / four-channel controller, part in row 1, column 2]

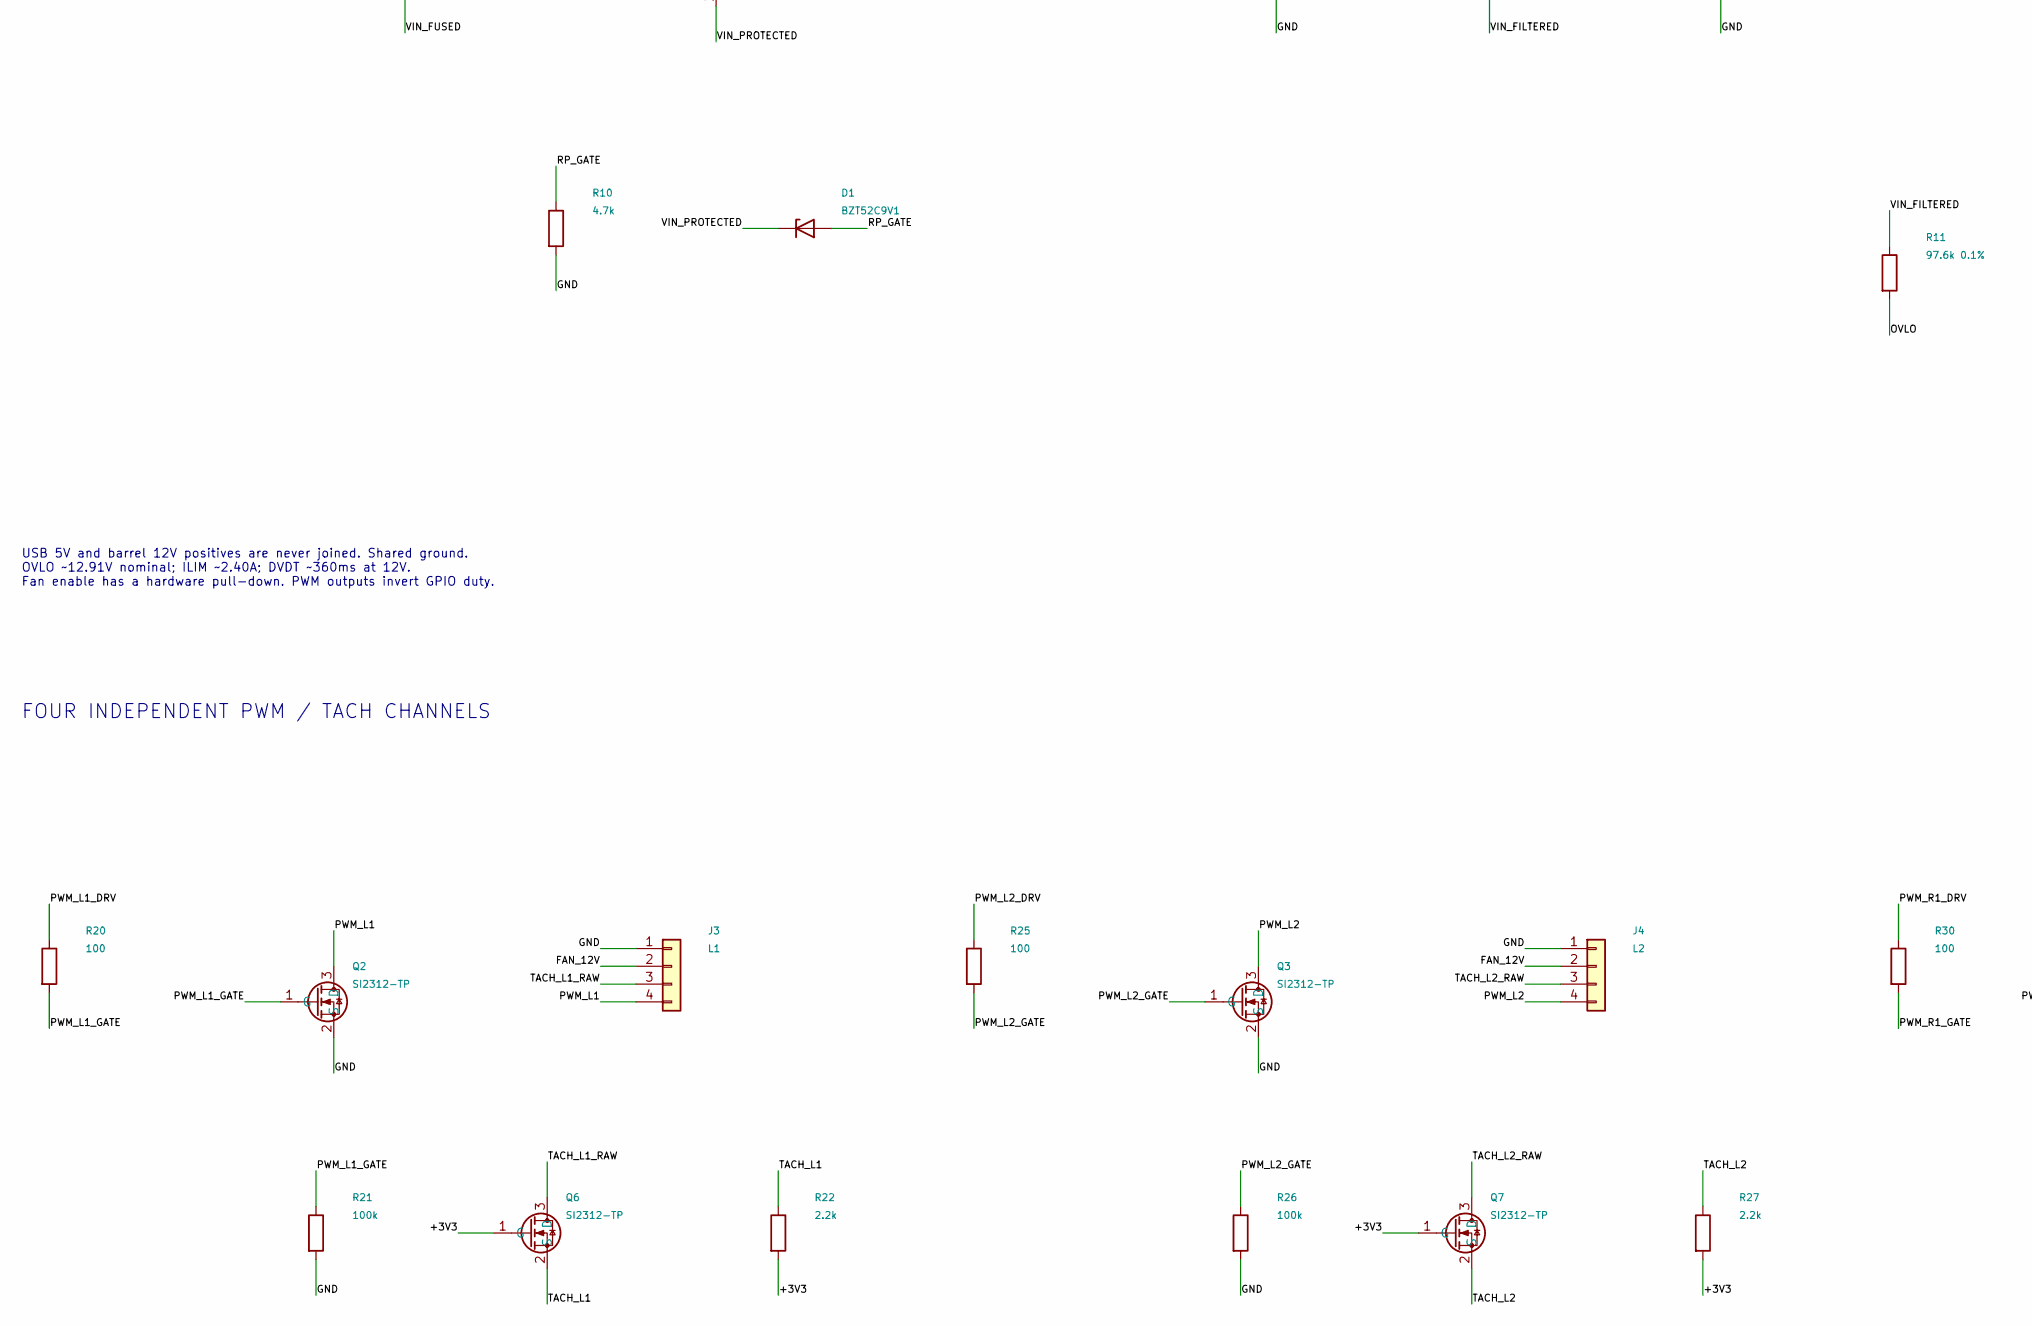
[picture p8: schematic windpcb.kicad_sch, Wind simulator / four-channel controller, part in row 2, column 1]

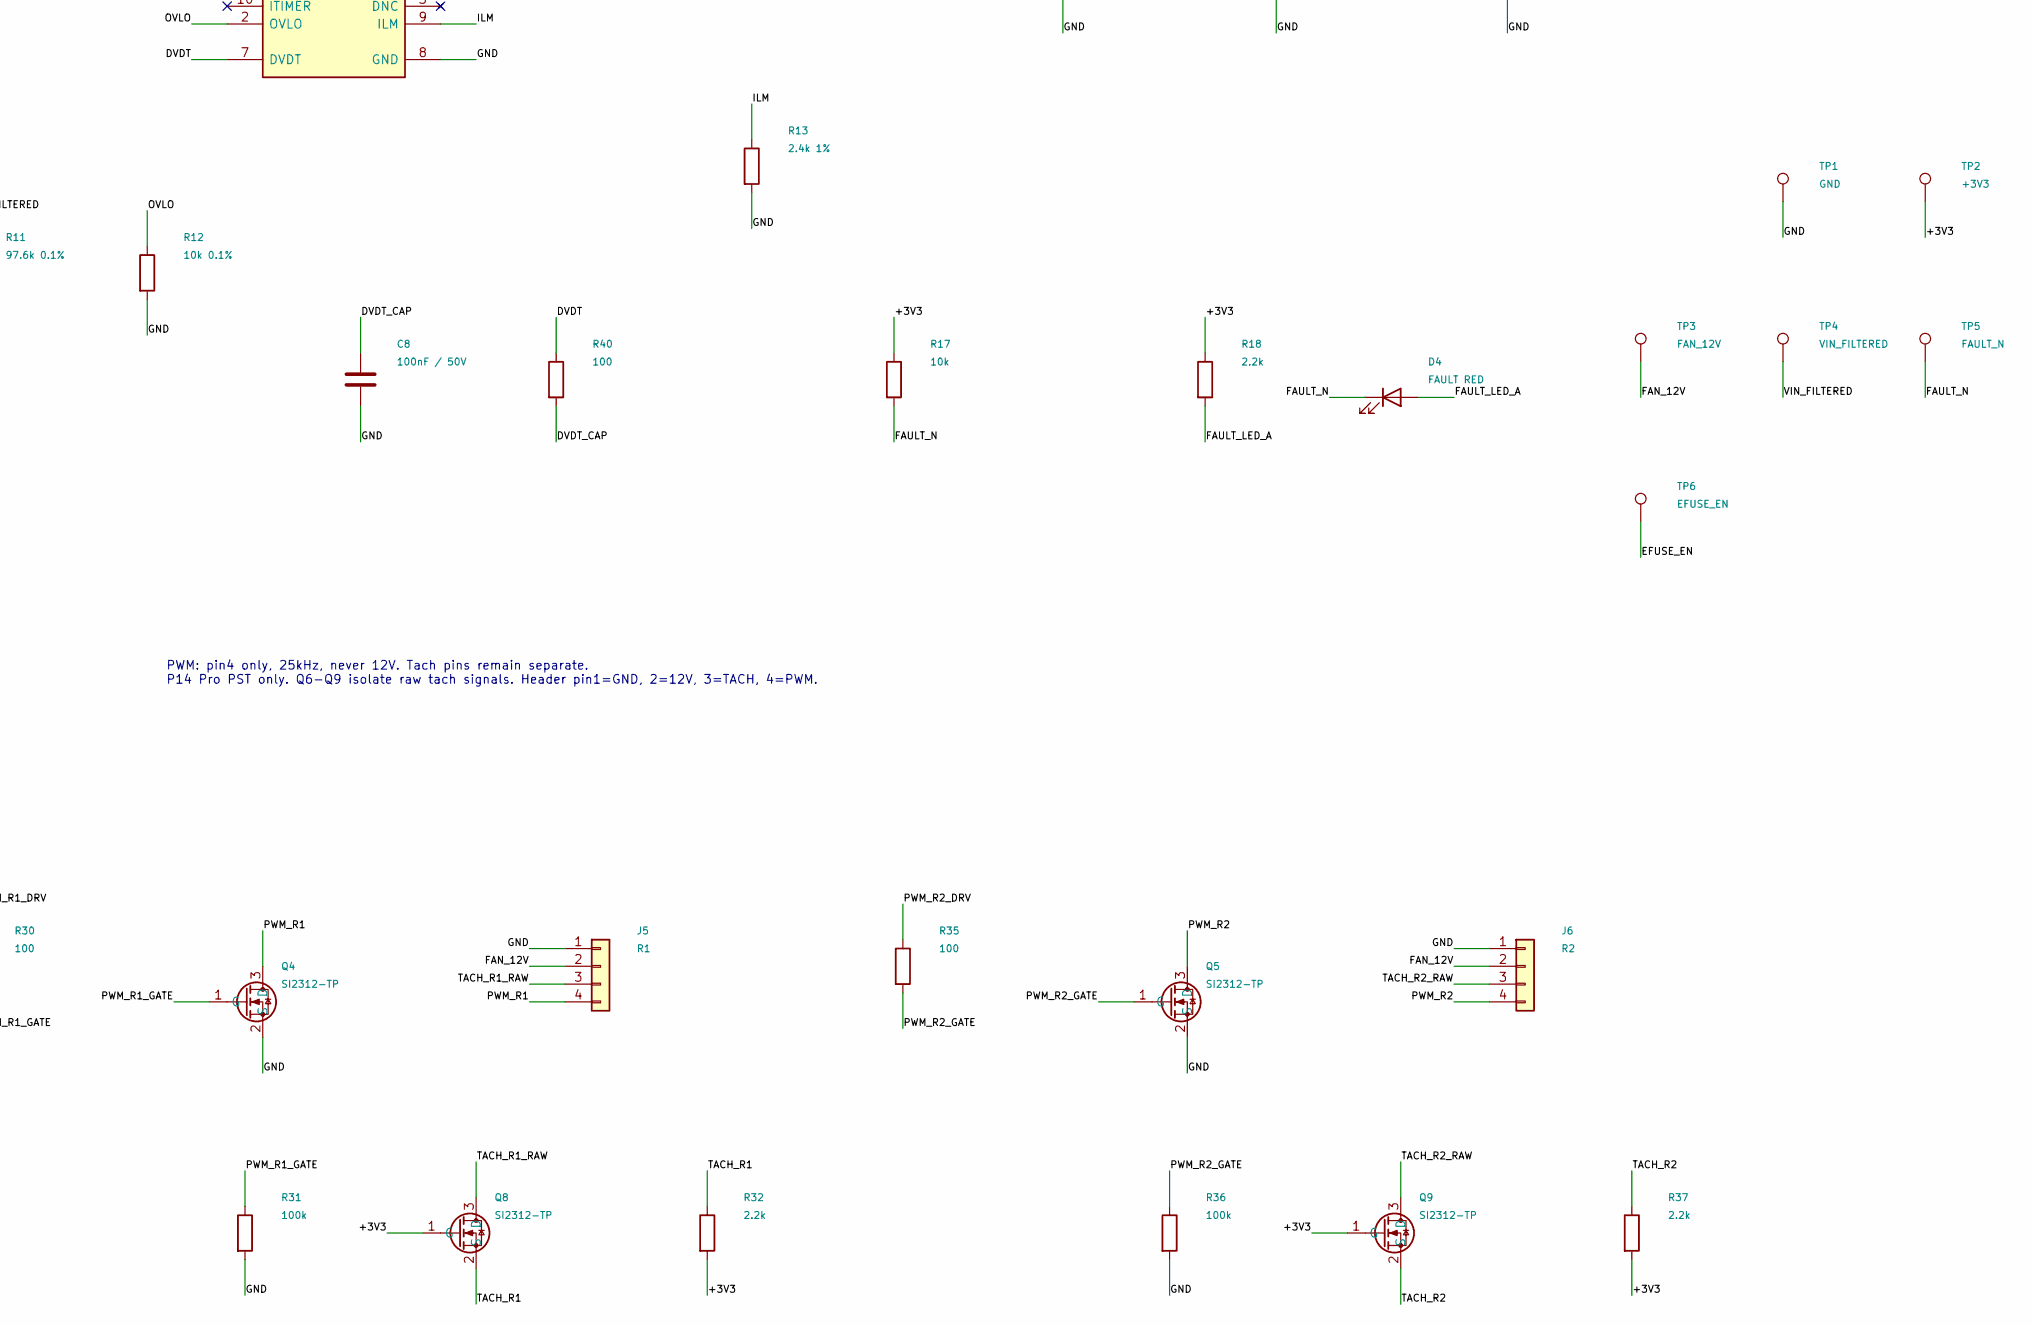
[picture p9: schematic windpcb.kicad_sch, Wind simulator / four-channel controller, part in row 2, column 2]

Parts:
C1, C2, C5: 1uF / 50V; Capacitor_SMD_C_0603_1608Metric; MPN CL10A105KB8NNNC; LCSC C15849
C3: 10uF / 50V; Capacitor_SMD_C_0805_2012Metric; MPN GRM21BR61H106KE43L; LCSC C440198
C4, C8, C11: 100nF / 50V; Capacitor_SMD_C_0603_1608Metric; MPN CC0603KRX7R9BB104; LCSC C14663
C6: 47uF / 50V; Capacitor_THT_CP_Radial_D6.3mm_P2.50mm; MPN EEUFR1H470; LCSC C407950
C7, C10: 1uF / 50V; Capacitor_SMD_C_0805_2012Metric; MPN CL21B105KBFNNNE; LCSC C28323
C9: 470uF / 25V; Capacitor_THT_CP_Radial_D10.0mm_P5.00mm; MPN EEUFR1E471; LCSC C407944
D1: BZT52C9V1; Diode_SMD_D_SOD-123; MPN BZT52C9V1-7-F; LCSC C260913
D2: SMBJ15A TVS; Diode_SMD_D_SMB; MPN SMBJ15A; LCSC C83846
D3: STATUS GREEN; LED_SMD_LED_0805_2012Metric; MPN KT-0805G; LCSC C2297
D4: FAULT RED; LED_SMD_LED_0603_1608Metric; MPN KT-0603R; LCSC C2286
F1: 3A / 32V; Fuse_Fuse_1206_3216Metric; MPN 0466003.NRHF; LCSC C14165
FB1: 120R@100MHz / 3.5A; Inductor_SMD_L_1206_3216Metric; MPN BLM31PG121SN1L; LCSC C85841
J1: 12V / CENTER +; BarrelJack_XKB_DC-005-5A-2.5; MPN DC-005-5A-2.5; LCSC C381115
J2: USB-C DATA; Connector_USB_USB_C_Receptacle_HRO_TYPE-C-31-M-12; MPN TYPE-C-31-M-12; LCSC C165948
J3: L1; Connector_FanPinHeader_1x04_P2.54mm_Vertical; MPN 470531000; LCSC C240840
J4: L2; Connector_FanPinHeader_1x04_P2.54mm_Vertical; MPN 470531000; LCSC C240840
J5: R1; Connector_FanPinHeader_1x04_P2.54mm_Vertical; MPN 470531000; LCSC C240840
J6: R2; Connector_FanPinHeader_1x04_P2.54mm_Vertical; MPN 470531000; LCSC C240840
Q1: AO3401A; Package_TO_SOT_SMD_SOT-23; MPN AO3401A; LCSC C15127
Q2, Q3, Q4, Q5, Q6, Q7, Q8, Q9: SI2312-TP; Package_TO_SOT_SMD_SOT-23; MPN SI2312-TP; LCSC C6488168
R1, R2: 5.1k; Resistor_SMD_R_0603_1608Metric; MPN 0603WAF5101T5E; LCSC C23186
R3, R4: 22; Resistor_SMD_R_0603_1608Metric; MPN 0603WAF220JT5E; LCSC C23345
R5, R6, R7, R8, R15, R17: 10k; Resistor_SMD_R_0603_1608Metric; MPN 0603WAF1002T5E; LCSC C25804
R9, R14, R19: 1k; Resistor_SMD_R_0603_1608Metric; MPN 0603WAF1001T5E; LCSC C21190
R10, R16: 4.7k; Resistor_SMD_R_0603_1608Metric; MPN 0603WAF4701T5E; LCSC C23162
R11: 97.6k 0.1%; Resistor_SMD_R_0603_1608Metric; MPN RT0603BRE0797K6L; LCSC C862326
R12: 10k 0.1%; Resistor_SMD_R_0603_1608Metric; MPN RT0603BRD0710KL; LCSC C95204
R13: 2.4k 1%; Resistor_SMD_R_0603_1608Metric; MPN 0603WAF2401T5E; LCSC C22940
R18, R22, R27, R32, R37: 2.2k; Resistor_SMD_R_0603_1608Metric; MPN 0603WAF2201T5E; LCSC C4190
R20, R25, R30, R35, R40: 100; Resistor_SMD_R_0603_1608Metric; MPN 0603WAF1000T5E; LCSC C22775
R21, R26, R31, R36: 100k; Resistor_SMD_R_0603_1608Metric; MPN 0603WAF1003T5E; LCSC C25803
SW1: BOOT; Button_Switch_SMD_SW_SPST_TL3342; MPN TL3342F160QG; LCSC C2886898
SW2: RESET; Button_Switch_SMD_SW_SPST_TL3342; MPN TL3342F160QG; LCSC C2886898
TP1: GND; TestPoint_TestPoint_Pad_D1.5mm; MPN PCB test point
TP2: +3V3; TestPoint_TestPoint_Pad_D1.5mm; MPN PCB test point
TP3: FAN_12V; TestPoint_TestPoint_Pad_D1.5mm; MPN PCB test point
TP4: VIN_FILTERED; TestPoint_TestPoint_Pad_D1.5mm; MPN PCB test point
TP5: FAULT_N; TestPoint_TestPoint_Pad_D1.5mm; MPN PCB test point
TP6: EFUSE_EN; TestPoint_TestPoint_Pad_D1.5mm; MPN PCB test point
U1: ESP32-C3-WROOM-02-N4; RF_Module_ESP32-C3-WROOM-02; MPN ESP32-C3-WROOM-02-N4; LCSC C2934560
U2: AP2112K-3.3; Package_TO_SOT_SMD_SOT-23-5; MPN AP2112K-3.3TRG1; LCSC C51118
U3: USBLC6-2SC6; Package_TO_SOT_SMD_SOT-23-6; MPN USBLC6-2SC6; LCSC C7519
U4: TPS25970LRPWR; TPS25970_RPW0010A_2x2mm; MPN TPS25970LRPWR; LCSC C3662801

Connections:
/+3V3: C2.1, C3.1, C4.1, Q6.1 (G), Q7.1 (G), Q8.1 (G), Q9.1 (G), R5.1, R6.1, R7.1, R8.1, R17.1, R18.1, R19.1, R22.2, R27.2, R32.2, R37.2, TP2.1, U1.1 (3V3), U2.5 (VOUT)
/BOOT_N: R6.2, SW1.1, U1.8 (IO9)
/CC1: J2.A5 (CC1), R1.1
/CC2: J2.B5 (CC2), R2.1
/DVDT: R40.1, U4.7 (DVDT)
/DVDT_CAP: C8.1, R40.2
/EFUSE_EN: C11.1, R14.2, R15.1, TP6.1, U4.1 (EN/UVLO)
/FAN_12V: C9.1, C10.1, J3.2, J4.2, J5.2, J6.2, R16.1, TP3.1, U4.6 (OUT)
/FAN_ENABLE: R14.1, U1.10 (IO10)
/FAULT_LED_A: D4.2 (A), R18.2
/FAULT_N: D4.1 (K), R17.2, TP5.1, U4.4 (~FAULT)
/GND: C1.2, C2.2, C3.2, C4.2, C5.2, C6.2, C7.2, C8.2, C9.2, C10.2, C11.2, D2.2 (A), D3.1 (K), J1.3, J2.A1 (GND), J2.A12 (GND), J2.B1 (GND), J2.B12 (GND), J2.SH (SHIELD), J3.1, J4.1, J5.1, J6.1, Q2.2 (S), Q3.2 (S), Q4.2 (S), Q5.2 (S), R1.2, R2.2, R10.2, R12.2, R13.2, R15.2, R16.2, R19.2, R21.2, R26.2, R31.2, R36.2, SW1.2, SW2.2, TP1.1, U1.9 (GND), U1.19 (GND), U2.2 (GND), U3.2 (GND), U4.8 (GND)
/ILM: R13.1, U4.9 (ILM)
/LED_A: D3.2 (A), R9.2
/MCU_EN: C5.1, R5.2, SW2.1, U1.2 (EN)
/OVLO: R11.2, R12.1, U4.2 (OVLO)
/PWM_L1: J3.4, Q2.3 (D)
/PWM_L1_DRV: R20.1, U1.3 (IO4)
/PWM_L1_GATE: Q2.1 (G), R20.2, R21.1
/PWM_L2: J4.4, Q3.3 (D)
/PWM_L2_DRV: R25.1, U1.4 (IO5)
/PWM_L2_GATE: Q3.1 (G), R25.2, R26.1
/PWM_R1: J5.4, Q4.3 (D)
/PWM_R1_DRV: R30.1, U1.5 (IO6)
/PWM_R1_GATE: Q4.1 (G), R30.2, R31.1
/PWM_R2: J6.4, Q5.3 (D)
/PWM_R2_DRV: R35.1, U1.6 (IO7)
/PWM_R2_GATE: Q5.1 (G), R35.2, R36.1
/RP_GATE: D1.2 (A), Q1.1 (G), R10.1
/STATUS_DRV: R9.1, U1.12 (IO21/TXD)
/STRAP2: R8.2, U1.16 (IO2)
/STRAP8: R7.2, U1.7 (IO8)
/TACH_L1: Q6.2 (S), R22.1, U1.18 (IO0)
/TACH_L1_RAW: J3.3, Q6.3 (D)
/TACH_L2: Q7.2 (S), R27.1, U1.17 (IO1)
/TACH_L2_RAW: J4.3, Q7.3 (D)
/TACH_R1: Q8.2 (S), R32.1, U1.15 (IO3)
/TACH_R1_RAW: J5.3, Q8.3 (D)
/TACH_R2: Q9.2 (S), R37.1, U1.11 (IO20/RXD)
/TACH_R2_RAW: J6.3, Q9.3 (D)
/USB_DN: R4.2, U1.13 (IO18)
/USB_DN_CONN: J2.A7 (D-), J2.B7 (D-), R4.1, U3.3 (I/O2), U3.4 (I/O2)
/USB_DP: R3.2, U1.14 (IO19)
/USB_DP_CONN: J2.A6 (D+), J2.B6 (D+), R3.1, U3.1 (I/O1), U3.6 (I/O1)
/USB_VBUS: C1.1, J2.A4 (VBUS), J2.A9 (VBUS), J2.B4 (VBUS), J2.B9 (VBUS), U2.1 (VIN), U2.3 (EN), U3.5 (VBUS)
/VIN_FILTERED: C7.1, FB1.2, R11.1, TP4.1, U4.5 (IN)
/VIN_FUSED: F1.2, Q1.3 (D)
/VIN_PROTECTED: C6.1, D1.1 (K), D2.1 (K), FB1.1, Q1.2 (S)
/VIN_RAW: F1.1, J1.1

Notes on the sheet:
USB-C DATA AND 3.3V LOGIC POWER
ESP32-C3 CONTROLLER
USB BOOT RECOVERY
PROTECTED 12V FAN POWER
FOUR INDEPENDENT PWM / TACH CHANNELS
Hold BOOT, tap RESET, release BOOT. ROM downloader works with blank flash. Connect USB only to program; barrel power is optional. GPIO2 and GPIO8 strap high. USB D-/D+ are GPIO18/19.
USB 5V and barrel 12V positives are never joined. Shared ground. OVLO ~12.91V nominal; ILIM ~2.40A; DVDT ~360ms at 12V. Fan enable has a hardware pull-down. PWM outputs invert GPIO duty.
PWM: pin4 only, 25kHz, never 12V. Tach pins remain separate. P14 Pro PST only. Q6-Q9 isolate raw tach signals. Header pin1=GND, 2=12V, 3=TACH, 4=PWM.

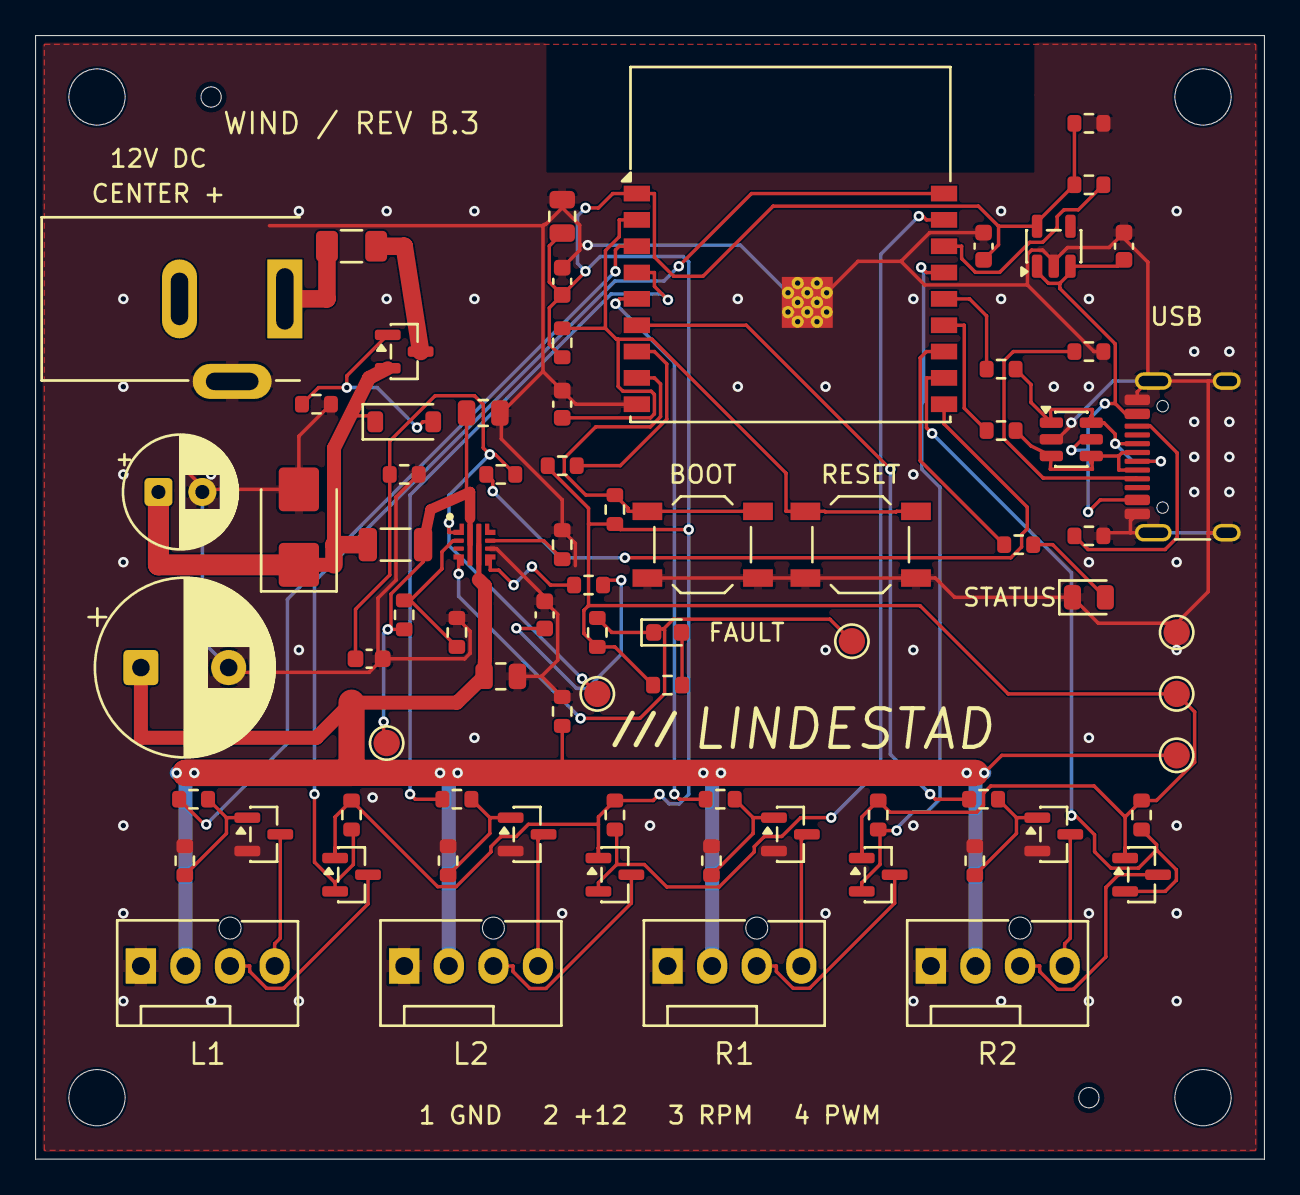
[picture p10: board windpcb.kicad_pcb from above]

Board: 2 copper layers, 70.0 x 64.0 mm, 82 parts (0 on the bottom side), 49 nets.

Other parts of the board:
H1, H2, H3, H4: M3; MountingHole_3.2mm_M3
H5, H6: JLC TOOL 1.152 NPTH; JLC_Tooling_1.152

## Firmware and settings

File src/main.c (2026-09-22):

#include "control.h"
#include <zephyr/kernel.h>
#include <zephyr/device.h>
#include <zephyr/drivers/gpio.h>
#include <zephyr/drivers/pwm.h>
#include <zephyr/drivers/uart.h>
#include <zephyr/drivers/watchdog.h>
#include <string.h>

#define USER DT_PATH(zephyr_user)
static const struct gpio_dt_spec enable = GPIO_DT_SPEC_GET(USER, fan_enable_gpios);
static const struct gpio_dt_spec status = GPIO_DT_SPEC_GET(USER, status_gpios);
static const struct gpio_dt_spec tach_pin[] = {
    GPIO_DT_SPEC_GET_BY_IDX(USER, tach_gpios, 0), GPIO_DT_SPEC_GET_BY_IDX(USER, tach_gpios, 1),
    GPIO_DT_SPEC_GET_BY_IDX(USER, tach_gpios, 2), GPIO_DT_SPEC_GET_BY_IDX(USER, tach_gpios, 3),
};
static const struct pwm_dt_spec pwm[] = {
    PWM_DT_SPEC_GET_BY_IDX(USER, 0), PWM_DT_SPEC_GET_BY_IDX(USER, 1),
    PWM_DT_SPEC_GET_BY_IDX(USER, 2), PWM_DT_SPEC_GET_BY_IDX(USER, 3),
};
static const struct device *const usb = DEVICE_DT_GET(DT_NODELABEL(usb_serial));
static const struct device *const watchdog = DEVICE_DT_GET(DT_NODELABEL(wdt0));
static struct gpio_callback tach_cb;
static volatile struct wind_tach tach[WIND_FANS];
static unsigned char status_frame[WIND_TELEMETRY_BYTES];
static unsigned status_sent, status_size;

static void status_irq(const struct device *dev, void *context)
{
    ARG_UNUSED(context);
    if (!uart_irq_update(dev) || !uart_irq_tx_ready(dev)) return;
    if (status_sent < status_size) {
        int sent = uart_fifo_fill(dev, status_frame + status_sent,
                                 (int)(status_size - status_sent));
        if (sent > 0) status_sent += (unsigned)sent;
    }
    if (status_sent == status_size) uart_irq_tx_disable(dev);
}

static void publish_status(const unsigned char *frame, unsigned size)
{
    // Keep at most one pending snapshot. Never wait for a host to read USB:
    // blocking poll_out can delay command expiry when USB is backpressured.
    unsigned key = irq_lock();
    if (status_sent == status_size) {
        memcpy(status_frame, frame, size);
        status_size = size;
        status_sent = 0;
        uart_irq_tx_enable(usb);
    }
    irq_unlock(key);
}

static void tach_edge(const struct device *dev, struct gpio_callback *cb, uint32_t pins)
{
    ARG_UNUSED(dev); ARG_UNUSED(cb);
    uint32_t now = k_uptime_get_32();
    for (unsigned i = 0; i < WIND_FANS; ++i) {
        if ((pins & BIT(tach_pin[i].pin)) &&
            (!tach[i].count || now - tach[i].last_ms >= 1U)) {
            tach[i].last_ms = now;
            tach[i].count++;
        }
    }
}

static int set_pwm(void *context, unsigned channel, uint32_t ns)
{
    ARG_UNUSED(context);
    return pwm_set_pulse_dt(&pwm[channel], ns);
}
static int set_enable(void *context, bool enabled)
{
    ARG_UNUSED(context);
    return gpio_pin_set_dt(&enable, enabled);
}
static const struct wind_io io = {.pwm = set_pwm, .enable = set_enable};

int main(void)
{
    struct wind_control state;
    wind_init(&state, k_uptime_get_32());
    if (!gpio_is_ready_dt(&enable) || gpio_pin_configure_dt(&enable, GPIO_OUTPUT_INACTIVE)) return 1;
    if (!device_is_ready(usb) || !device_is_ready(watchdog)) return 2;
    for (unsigned i = 0; i < WIND_FANS; ++i) if (!pwm_is_ready_dt(&pwm[i])) return 3;
    if (wind_apply(&state.output, &io)) return 4;
    if (uart_irq_callback_user_data_set(usb, status_irq, NULL)) return 12;
    if (!gpio_is_ready_dt(&status) || gpio_pin_configure_dt(&status, GPIO_OUTPUT_INACTIVE)) return 5;
    uint32_t mask = 0;
    for (unsigned i = 0; i < WIND_FANS; ++i) {
        if (!gpio_is_ready_dt(&tach_pin[i]) || gpio_pin_configure_dt(&tach_pin[i], GPIO_INPUT)) return 6;
        mask |= BIT(tach_pin[i].pin);
    }
    gpio_init_callback(&tach_cb, tach_edge, mask);
    if (gpio_add_callback(tach_pin[0].port, &tach_cb)) return 7;
    for (unsigned i = 0; i < WIND_FANS; ++i)
        if (gpio_pin_interrupt_configure_dt(&tach_pin[i], GPIO_INT_EDGE_FALLING)) return 8;
    // ESP32 driver has an interrupt stage followed by a system-reset stage.
    // 500 ms per stage: do not claim a 500 ms total watchdog reset latency.
    struct wdt_timeout_cfg timeout = {
        .window = {.min = 0, .max = 500}, .flags = WDT_FLAG_RESET_SOC,
    };
    int channel = wdt_install_timeout(watchdog, &timeout);
    if (channel < 0 || wdt_setup(watchdog, 0)) return 9;
    unsigned char byte;
    unsigned discarded = 0;
    while (discarded < 256U && !uart_poll_in(usb, &byte)) discarded++;
    if (discarded == 256U) wind_fault(&state, true);
    uint32_t last_status = k_uptime_get_32() - WIND_STATUS_MS;
    uint32_t last_rpm = k_uptime_get_32();
    uint32_t prior_count[WIND_FANS] = {0}, rpm[WIND_FANS] = {0};
    for (;;) {
        struct wind_tach snapshot[WIND_FANS];
        unsigned key = irq_lock();
        for (unsigned i = 0; i < WIND_FANS; ++i) snapshot[i] = tach[i];
        irq_unlock(key);
        uint32_t now = k_uptime_get_32();
        wind_tick(&state, now, snapshot);
        unsigned received = 0;
        while (received < 64U && !uart_poll_in(usb, &byte)) {
            wind_byte(&state, byte, k_uptime_get_32());
            received++;
        }
        if (received == 64U) wind_fault(&state, true);
        wind_tick(&state, k_uptime_get_32(), snapshot);
        if (wind_apply(&state.output, &io)) {
            (void)gpio_pin_set_dt(&enable, false);
            return 10; // no watchdog feed after an actuator failure
        }
        (void)gpio_pin_set_dt(&status, state.output.enable);
        now = k_uptime_get_32();
        if (now - last_status >= WIND_STATUS_MS) {
            unsigned char frame[WIND_TELEMETRY_BYTES];
            wind_status(&state, frame);
            unsigned size = WIND_STATUS_BYTES;
            if (now - last_rpm >= 1000U) {
                for (unsigned i = 0; i < WIND_FANS; ++i) {
                    rpm[i] = wind_rpm(snapshot[i].count - prior_count[i], now - last_rpm);
                    prior_count[i] = snapshot[i].count;
                }
                last_rpm = now;
                size += wind_telemetry(&state, rpm, now, frame + size,
                                       (unsigned)sizeof(frame) - size);
            }
            publish_status(frame, size);
            last_status = now;
        }
        if (wdt_feed(watchdog, channel)) {
            struct wind_output stopped = {0};
            (void)wind_apply(&stopped, &io);
            return 11;
        }
        k_msleep(5);
    }
}

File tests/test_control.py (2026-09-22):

"""Execute the actual C control/output code on the host; no Zephyr mocks of its logic."""
import ctypes as C
import json
from pathlib import Path
import random
import re
import shutil
import subprocess
import unittest

ROOT = Path(__file__).resolve().parents[1]
BUILD = ROOT / 'tests/.build'
BUILD.mkdir(exist_ok=True)
gcc = shutil.which('gcc')
if not gcc:
    raise RuntimeError('A host GCC is required for these executable C tests')
subprocess.run([gcc, '-std=c11', '-Wall', '-Wextra', '-Werror', '-Wconversion', '-O2',
                '-shared', '-I'+str(ROOT/'include'), str(ROOT/'src/control.c'),
                str(ROOT/'src/output.c'), str(ROOT/'tests/host.c'),
                '-o', str(BUILD/'control.dll')], check=True)
lib = C.CDLL(str(BUILD/'control.dll'))
for name, argc in [('host_init',1),('host_byte',2),('host_tick',1),('host_edge',2),
                   ('host_demand',1),('host_target',1),('host_fault',1)]:
    getattr(lib,name).argtypes = [C.c_uint32]*argc
lib.host_starting.restype = C.c_int
lib.host_status.argtypes = [C.POINTER(C.c_ubyte)]
lib.host_telemetry.argtypes = [C.POINTER(C.c_ubyte), C.c_uint32]
lib.host_rpm.argtypes = [C.c_uint32, C.c_uint32]

def frame(left=600, right=700, now=0):
    raw = f'W,{left},{right}\n'.encode()
    for byte in raw: lib.host_byte(byte,now)

def feed(raw, now=0):
    for byte in raw: lib.host_byte(byte,now)

def outputs(): return [lib.host_demand(i) for i in range(4)]

def run_until(end, start=0, left=600, right=700, tach=True, origin=0, present=15):
    for elapsed in range(start,end+1,10):
        now=(origin+elapsed)&0xffffffff
        if elapsed%100==0: frame(left,right,now)
        if tach and elapsed%20==0:
            for i,demand in enumerate(outputs()):
                if demand and present & (1 << i): lib.host_edge(i,now)
        lib.host_tick(now)

class ControlTests(unittest.TestCase):
    def setUp(self): lib.host_init(0)

    def test_boot_and_console_noise_cannot_start(self):
        feed(b'ESP-ROM:esp32c3\nhello\nW,-1,0\nW,1001,0\n')
        self.assertFalse(lib.host_enable()); self.assertEqual(lib.host_accepted(),0)
        self.assertEqual(outputs(),[0]*4)

    def test_precharge_and_250ms_kick(self):
        run_until(740)
        self.assertTrue(lib.host_enable()); self.assertEqual(outputs(),[0]*4)
        run_until(750,750); self.assertEqual(outputs(),[1000,0,0,0])
        run_until(990,760); self.assertEqual(outputs(),[1000,0,0,0])
        run_until(1000,1000); self.assertEqual(outputs(),[600,0,0,0])

    def test_four_fans_start_at_least_500ms_apart(self):
        first=[None]*4
        for ms in range(0,2510,10):
            run_until(ms,ms)
            for i,d in enumerate(outputs()):
                if d and first[i] is None: first[i]=ms
        self.assertEqual(first,[750,1250,1750,2250])
        self.assertEqual(outputs(),[600,600,700,700])

    def test_no_tach_warns_and_advances_without_repeated_kicks(self):
        run_until(2750,tach=False)
        self.assertEqual(lib.host_mode(),2); self.assertTrue(lib.host_enable())
        self.assertEqual(lib.host_warnings(),1)
        self.assertEqual(outputs(),[600,1000,0,0])
        run_until(15000,2760,tach=False)
        self.assertEqual(lib.host_warnings(),15)
        self.assertEqual(outputs(),[600,600,700,700])
        self.assertEqual(lib.host_starting(),-1)

    def test_all_sixteen_fan_populations(self):
        for present in range(16):
            with self.subTest(present=present):
                lib.host_init(0)
                run_until(10000,present=present)
                self.assertEqual(lib.host_mode(),2)
                self.assertTrue(lib.host_enable())
                self.assertEqual(outputs(),[600,600,700,700])
                self.assertEqual(lib.host_warnings(),15 ^ present)

    def test_warning_clears_only_after_three_new_edges(self):
        run_until(4000,left=600,right=0,present=1)
        self.assertEqual(lib.host_warnings(),2)
        lib.host_edge(1,4010); lib.host_tick(4010)
        lib.host_edge(1,4020); lib.host_tick(4020)
        self.assertEqual(lib.host_warnings(),2)
        lib.host_edge(1,4030); lib.host_tick(4030)
        self.assertEqual(lib.host_warnings(),0)
        self.assertEqual(outputs(),[600,600,0,0])

    def test_warning_clears_on_side_stop_and_rechecks_on_restart(self):
        run_until(10000,present=1)
        self.assertEqual(lib.host_warnings(),14)
        frame(0,700,10010); lib.host_tick(10010)
        self.assertEqual(lib.host_warnings(),12)
        frame(600,700,10020); lib.host_tick(10020)
        self.assertEqual(outputs()[0],1000)
        run_until(15000,10030,present=1)
        self.assertEqual(lib.host_warnings(),14)
        frame(0,0,15010)
        self.assertEqual(lib.host_warnings(),0)
        self.assertFalse(lib.host_enable())

    def test_warning_does_not_bypass_command_timeout_or_hard_fault(self):
        run_until(10000,tach=False)
        lib.host_tick(10500)
        self.assertEqual(lib.host_mode(),3)
        self.assertEqual(outputs(),[0]*4)
        self.assertEqual(lib.host_warnings(),0)
        frame(500,500,10510); lib.host_fault(1)
        self.assertEqual(lib.host_mode(),4)
        self.assertFalse(lib.host_enable())

    def test_status_protocol_reports_mode_and_warning_mask(self):
        out=(C.c_ubyte*8)()
        lib.host_status(out); self.assertEqual(bytes(out),b'S,1,0,0\n')
        run_until(10000,present=5)
        lib.host_status(out); self.assertEqual(bytes(out),b'S,1,2,A\n')
        lib.host_tick(10500)
        lib.host_status(out); self.assertEqual(bytes(out),b'S,1,3,0\n')
        lib.host_fault(1)
        lib.host_status(out); self.assertEqual(bytes(out),b'S,1,4,0\n')

    def test_rpm_window_and_telemetry(self):
        self.assertEqual(lib.host_rpm(100,1000),3000)
        self.assertEqual(lib.host_rpm(101,1010),3000)
        self.assertEqual(lib.host_rpm(0,1000),0)
        self.assertEqual(lib.host_rpm(100,0),0)
        self.assertEqual(lib.host_rpm(0xffffffff,1),30000)
        out=(C.c_ubyte*128)()
        size=lib.host_telemetry(out,128)
        self.assertEqual(bytes(out[:size]), b'T,2,0,0,123456,0,0,0,1200,1500,3000,0,0,0,0\n')
        self.assertEqual(lib.host_telemetry(out,8),0)

    def test_two_edges_are_not_two_periods(self):
        run_until(750,tach=False)
        lib.host_edge(0,800); lib.host_edge(0,900)
        run_until(1250,760,tach=False)
        self.assertEqual(lib.host_starting(),0); self.assertEqual(outputs()[1],0)
        lib.host_edge(0,1260); lib.host_tick(1260)
        self.assertEqual(lib.host_starting(),1)

    def test_old_edges_do_not_qualify_new_start(self):
        for _ in range(20): lib.host_edge(0,0)
        run_until(1250,tach=False)
        self.assertEqual(lib.host_starting(),0)
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

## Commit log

2026-09-07 add wind controller firmware and pre-order checks
    [wind_controller.yaml]
2026-09-22 allow missing fans and report tach warnings
    [audit_build.py, main.c, stop_for_flash.py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]
2026-09-22 report fan rpm and controller telemetry
2026-09-22 publish reproducible pcb and firmware sources
    [BOM.csv, HAND-BOM.csv, KiCad-positions.csv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]
2026-09-22 pin tested companion integration
